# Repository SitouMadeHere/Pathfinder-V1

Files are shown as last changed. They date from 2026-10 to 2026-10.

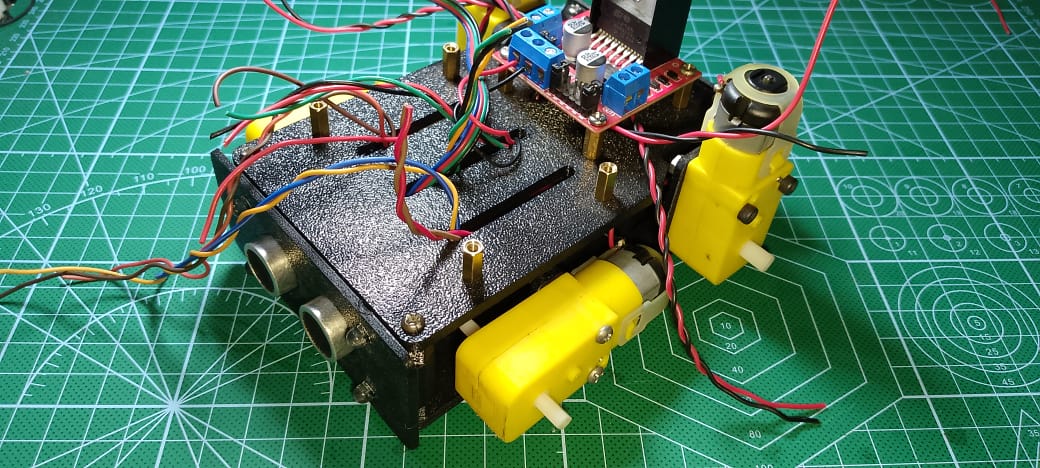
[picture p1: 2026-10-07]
Assembly2.jpeg

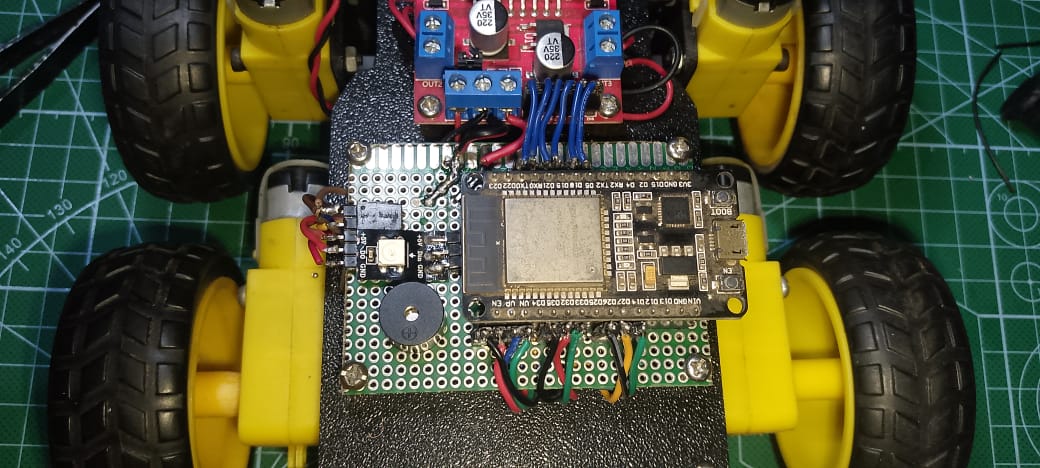
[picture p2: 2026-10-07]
Assembly1.jpeg

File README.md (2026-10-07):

# Pathfinder 

**Pathfinder** is an educational mobile robot designed as a learning by doing platform for exploring:

* Robotics
* Embedded programming
* Electronics
* Sensors and actuators
* Motor control
* 3D CAD
* FDM 3D printing
* Digital fabrication

The project is intended for **educational use and experimentation**.
> I've designed this robot for learning and experimentation and it a perfect educational project for learning by doing .

## Features

Pathfinder supports three operating modes:

* 🟢 **Automatic** — the robot detects obstacles, follows objects, and can detect drop-offs.
* 🔵 **Semi-automatic** — the operator controls the robot while the system helps maintain a minimum distance from obstacles.
* 🔴 **Manual** — full manual control without assistance.

The robot also includes:

* Ultrasonic obstacle detection
* Infrared drop-off detection
* Front and back signal LEDs
* WS2812B RGB status LED
* Buzzer
* Smartphone control via **Dabble app**
* 4-wheel drive

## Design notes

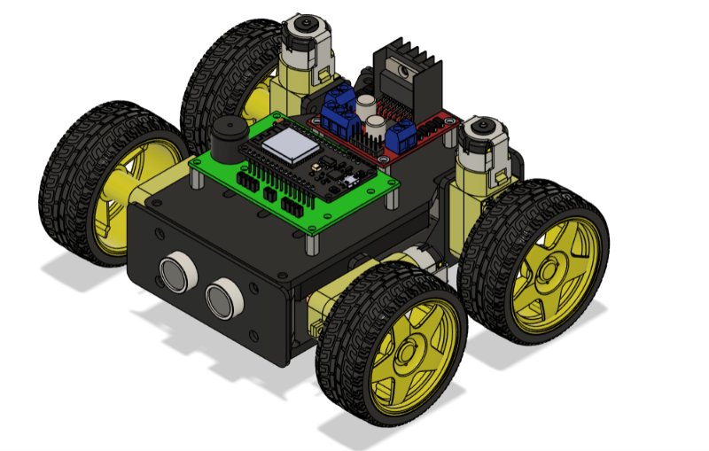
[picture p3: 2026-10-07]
view3.png

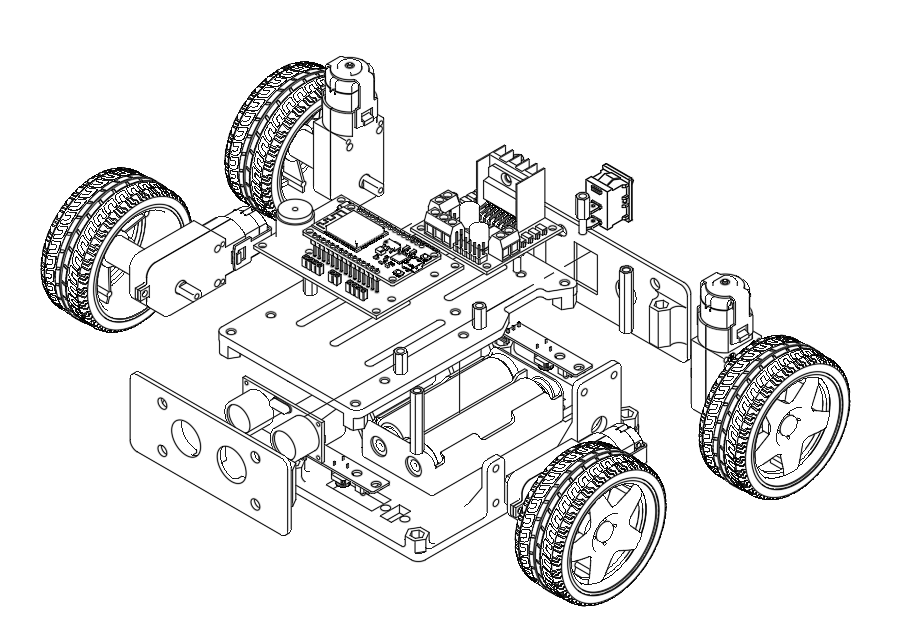
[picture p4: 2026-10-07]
view2.png

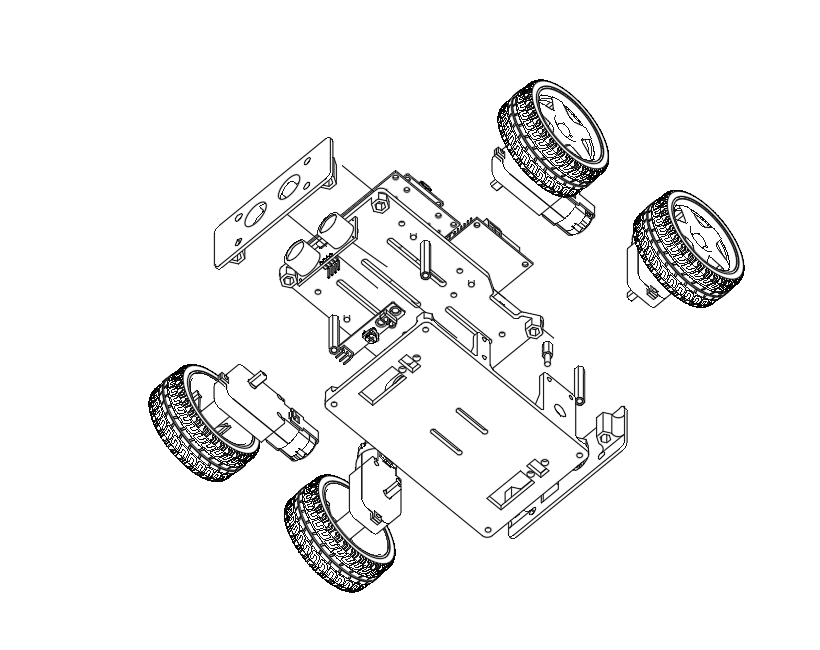
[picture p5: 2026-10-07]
view1.png

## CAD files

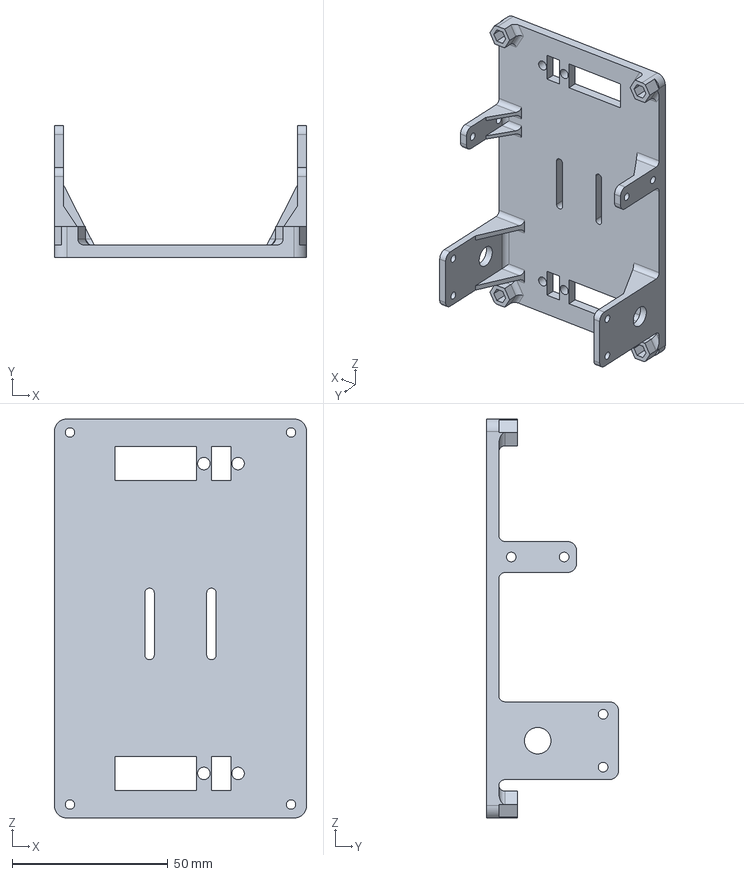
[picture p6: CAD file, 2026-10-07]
COMPOSENT/BASE.step
81.0 x 42.5 x 128.2 mm

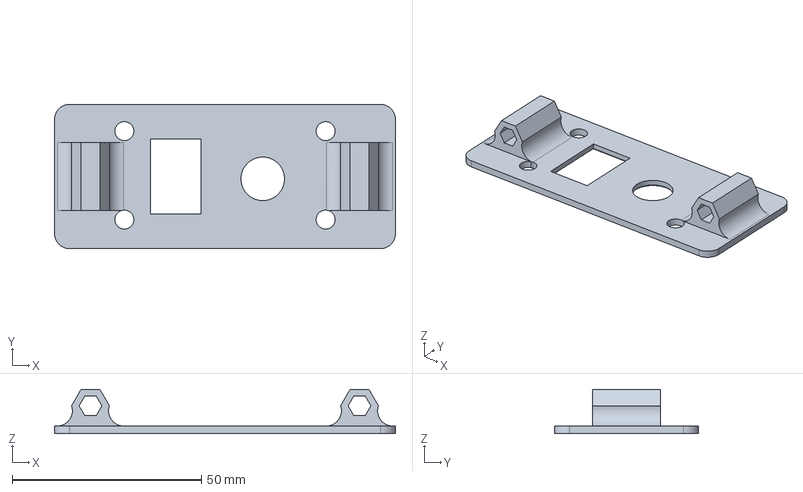
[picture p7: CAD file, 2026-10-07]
COMPOSENT/Back.step
90.0 x 38.1 x 11.7 mm

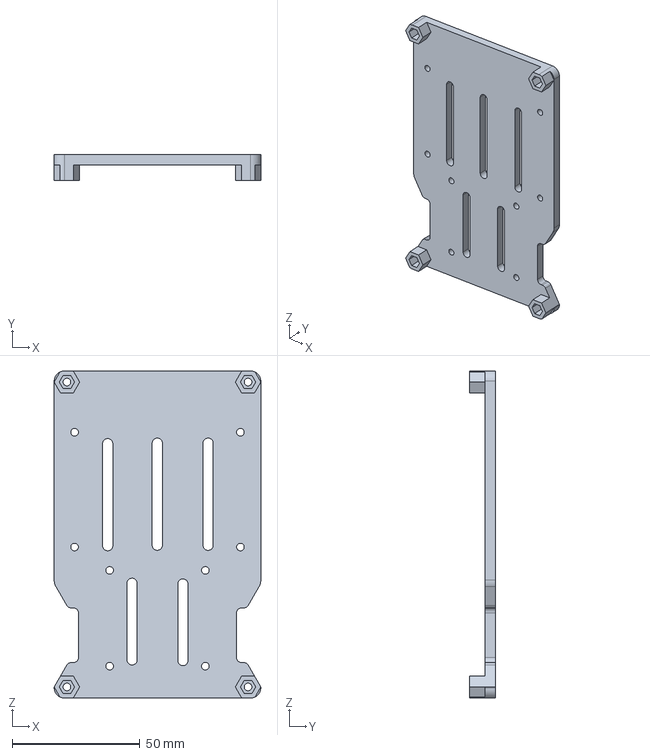
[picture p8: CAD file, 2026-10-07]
COMPOSENT/TOP FRAME.step
81.0 x 10.0 x 128.2 mm

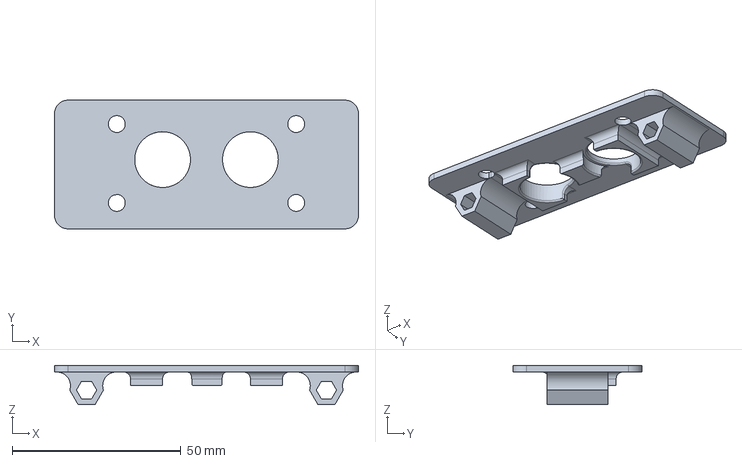
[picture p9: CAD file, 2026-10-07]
COMPOSENT/Front.step
90.0 x 38.1 x 11.7 mm

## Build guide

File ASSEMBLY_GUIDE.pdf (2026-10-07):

### B U I L D G U I D E

# Robot Pathfinder

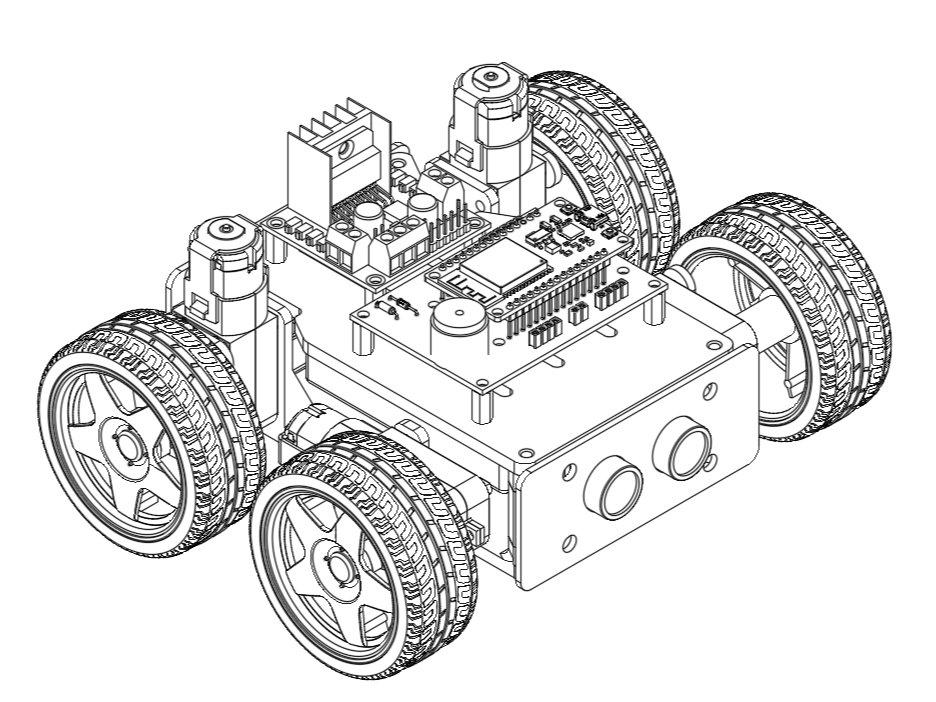
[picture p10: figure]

“Great discoveries and improvements invariably involve the cooperation of many minds.”

Alexander Graham Bell

P A T H F I N D E R | Build guide
Educational use | Page 2 / 13

# Contents

## 1. Introduction

This robot is intended for educational use only. It is named Pathfinder, after the Mars rover of the same name. Its overall dimensions are 180 × 150 × 90 mm and it incorporates numerous sensors dedicated to obstacle detection.

The robot can be used in three operating modes:

Mode | Description

Automatic

The robot is constantly alert and reacts to obstacles on its own: it detects obstacles, follows an object and can also detect drop-offs.

Semi-automatic (assisted
driving)

The operator drives the robot, but the system enforces minimum distances from obstacles to keep the robot and bystanders safe.

Manual (free driving) The operator keeps full control of the robot, with no restrictions.

Note Drop-off detection is disabled by default. To enable it, uncomment the corresponding section in the code.

## 2. Technical specifications

Characteristic | Specification
CAD software | Autodesk Fusion 360
Manufacturing process | 3D printing (FDM)
Recommended material | Filament PETG (preferred): excellent mechanical strength and good impact durability
Overall dimensions | 180 mm (length) × 150 mm (width) × 90 mm (height)

## 3. Bill of materials (BOM)

The table below lists all the components required to build the robot.

No. | Component | Reference / Description | Qty
1 | Microcontroller | ESP32 Dev Module | 1
2 | Motor | DC gear motor | 4
3 | Motor driver | L293N | 1
4 | Ultrasonic sensor | HC-SR04 | 1
5 | Infrared (IR) sensor | TCRT5000 | 2
6 | White LED | 5 mm, 5 V DC | 4
7 | Red LED | 5 mm, 5 V DC | 4
8 | RGB LED | WS2812B | 1
9 | Resistor | 220 Ω | 4
10 | Diode | 1N4007 | 1
11 | Female power jack | 2.1 × 5.5 mm, round, off-center | 1
12 | Mini ON/OFF switch | KCD11, 3 A / 250 V, 2 or 3 pins | 1
13 | Lithium battery | 18650 | 2
14 | Electrical wire | — | As needed
15 | Phillips or hex screw | M3-30 | 8
16 | Phillips or hex screw | M3-8 | 16
17 | Flat-head screw | M3-10 | 2
18 | Female-female hex standoff | M3-30 | 4
19 | Male-female hex standoff | M3-12 | 8
20 | Female pin header | 1 × 40 pins | 2
21 | Male pin header | 1 × 40 pins | 2

## 4. Assembly guide

Note All the parts that make up the robot’s structure are available in the “Composent” folder. If the parts fit tightly during assembly, do not hesitate to enlarge the holes slightly.

### Step 1: Mounting the motors

Solder wires of sufficient length onto each motor, then fasten them to the chassis with M3-30 screws, in the direction shown in the illustration.

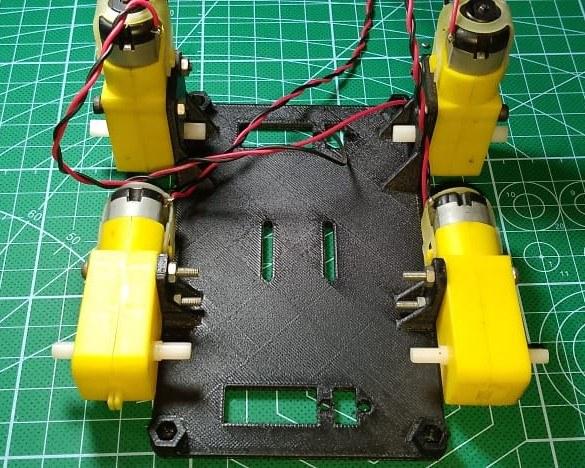
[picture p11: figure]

Figure 1 — Motors mounted on the chassis

### Step 2: Infrared sensors and battery holder

Solder electrical wires onto the infrared (IR) sensors, then screw them onto the chassis together with the M3-30 hex standoffs. Then attach the battery holder with M3 flat-head screws.

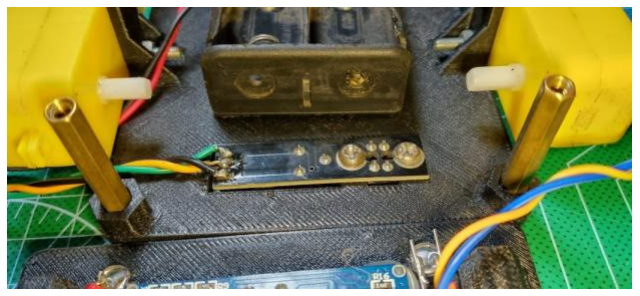
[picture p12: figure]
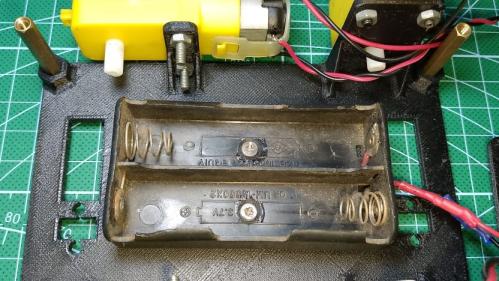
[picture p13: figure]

Figure 2 — IR sensors and M3-30 standoffs | Figure 3 — Battery holder

### Step 3: Fitting out the front and rear covers

Following the wiring diagram (section 5), solder the power jack, the switch and the four red LEDs, then install them in the rear cover. Next, solder the wires to the ultrasonic sensor and the four white LEDs, then install them in the front cover.

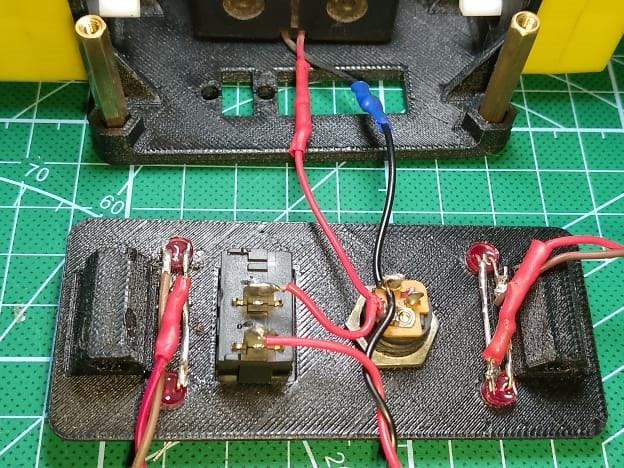
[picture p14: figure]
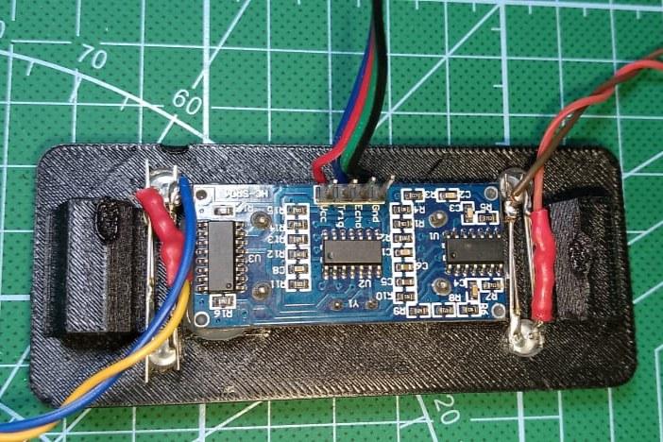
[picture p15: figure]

Figure 4 — Rear cover fitted | Figure 5 — Front cover fitted

Result At this point, the basic structure is mechanically ready and all front and rear peripherals are installed.

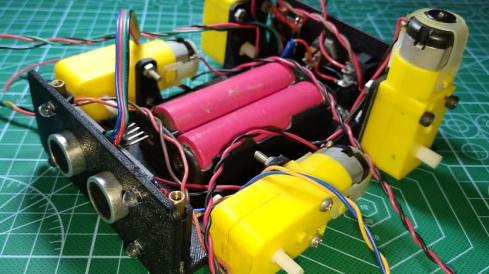
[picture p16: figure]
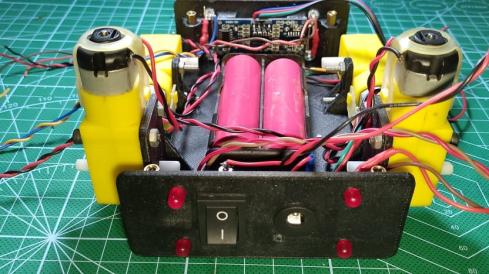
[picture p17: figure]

Figure 6 — Basic structure, front view | Figure 7 — Basic structure, rear view

### Step 4: Closing the chassis

Place the roof on the chassis, making sure all the wires come out: the motor wires through the rear slots and the other cables through the front slots. Screw in the eight M3-12 standoffs and attach the motor driver module (see the bill of materials). Finally, insert all the M3 screws and tighten them to permanently join the roof to the chassis.

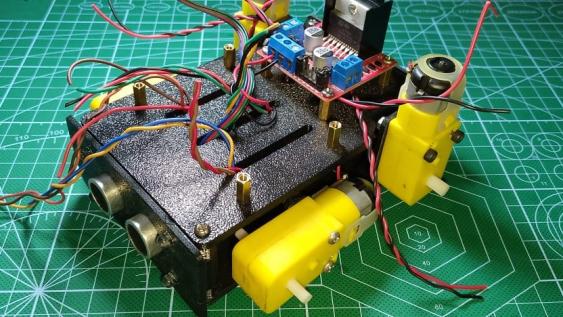
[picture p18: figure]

Figure 8 — Robot assembled with the roof and motor driver

## 5. Electronic circuit and main board

This section gathers all the diagrams and electrical connections of the robot.

### 5.1 Electronic circuit

Battery wiring
The diagram below shows the wiring of the battery (BT1), the power jack (J1) and the switch (SW1).

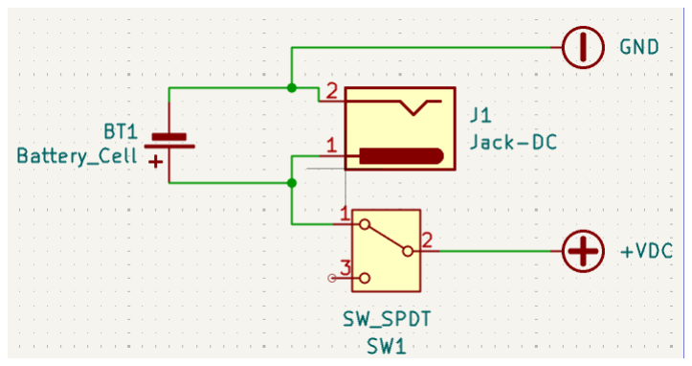
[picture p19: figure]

Figure 9 — Battery wiring diagram

LED wiring
The robot’s lighting system is divided into four (04) independent groups. Each group consists of two (02) LEDs wired in parallel, the whole being placed in series with a 220 Ω resistor.

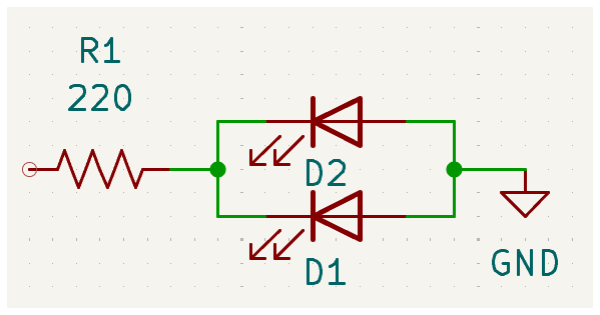
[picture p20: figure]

Figure 10 — Wiring diagram of one LED group

### 5.2 Main board

The main board is based on a 30-pin ESP32. All peripheral components are connected to it through male and female connectors carrying signals and power.

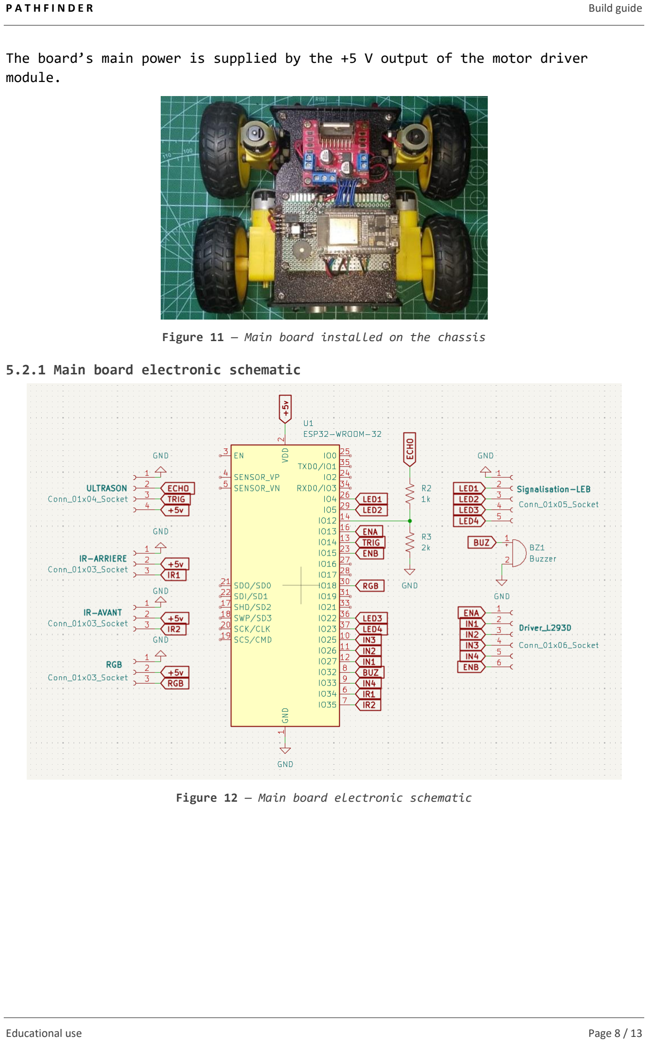
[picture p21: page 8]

The board’s main power is supplied by the +5 V output of the motor driver module.

Figure 11 — Main board installed on the chassis

### 5.2.1 Main board electronic schematic

Figure 12 — Main board electronic schematic

### 5.2.2 ESP32-to-driver connection

Connect a 6-pin female connector to a 6-pin male connector to link the ESP32 and the motor driver.

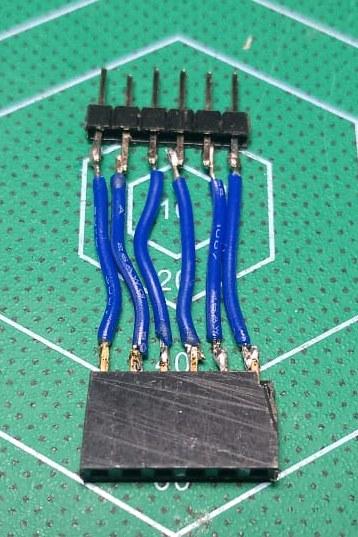
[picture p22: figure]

Figure 13 — 6-pin
connector

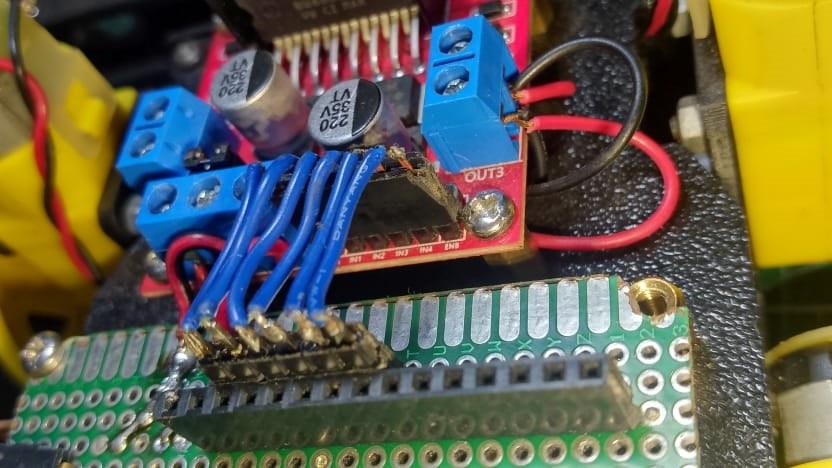
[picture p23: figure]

Figure 14 — Link to the motor driver

### 5.2.3 RGB LED connection

This is a WS2812B LED soldered onto a 3-pin male connector.

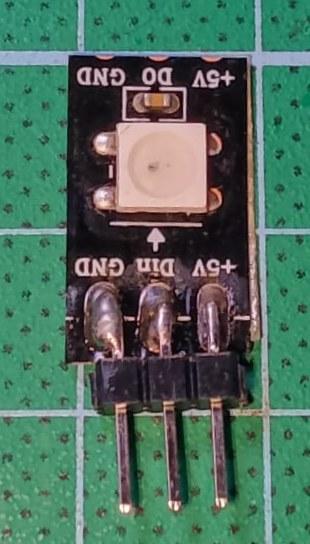
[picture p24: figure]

Figure 15 — WS2812B RGB LED module

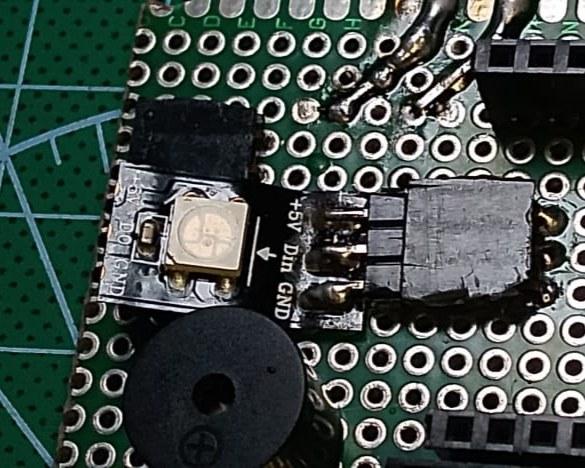
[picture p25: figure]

Figure 16 — Module installed on the main board

### 5.2.4 Signal LED connection

These are the LEDs built into the robot’s front and rear covers. They are connected to the main board through male-female connectors, following the wiring diagram defined on the board.

To wire the LEDs to the connector:

- Connect all the LED grounds (GND) together, then make a common solder joint to the connector’s ground pin.

- Then solder the LED control outputs to the adjacent connector pins, in the following order:

### 1. Front cover, left LED 2. Front cover, right LED 3. Rear cover, left LED 4. Rear cover, right LED

Important Respect the connection order and the LED polarity to ensure compatibility with the main board’s electrical schematic.

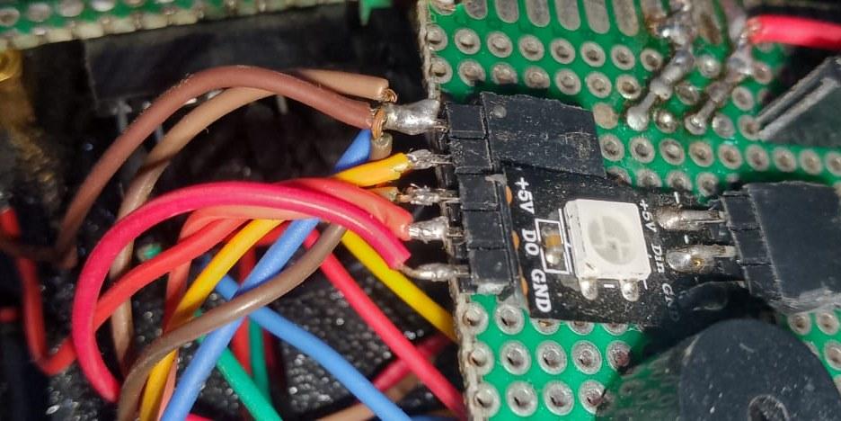
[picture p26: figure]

Figure 17 — Signal LED connections

### 5.3 IR sensor calibration

The infrared sensors must be calibrated to detect changes in distance between the robot and the surface it moves on. The goal is to identify any significant height difference indicating that part of the robot is over a void, or that the robot is abnormally raised.

Calibration consists of adjusting the potentiometer on each IR sensor to set the detection threshold correctly.

1. Power on the sensors and place the robot on a flat, uniform surface.
2. Observe the indicator LED on the IR module.

### 3. Slowly turn the potentiometer until the sensor reliably detects the surface

beneath the robot.

### 4. Gradually move the sensor toward an area simulating a void (table edge, a

black sheet held far away, or removing the surface under the sensor).

### 5. Adjust the potentiometer until the sensor’s state changes exactly when the

reference surface disappears.
6. Repeat several times, alternating the presence and absence of the surface, to check that detection is stable.
7. Make the same adjustment on the second IR sensor.

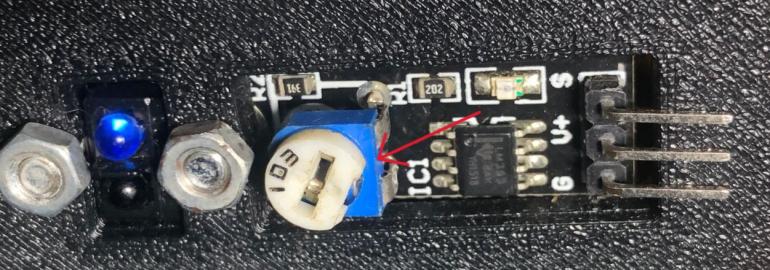
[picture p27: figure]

Figure 18 — TCRT5000 IR sensor and its adjustment potentiometer

## 6. Programs and source code

This section presents the programs required to run the robot. All files are available in the Code source folder.

### 6.1 Important tips

Uploading It is strongly recommended to remove the ESP32 board from its socket before uploading any code. Likewise, always switch the system off before putting it back.

Tests Run unit tests on each module to verify that it works correctly on its own.

Compilation Before compiling the code, install version 2.0.17 of the ESP32 package in the Boards Manager. If a newer version is installed, it is recommended to uninstall it to avoid compatibility conflicts.

### 6.2 Main programs

Program | Role
Auto-code | Manages the robot’s full autonomy.

Mode-code

Smartphone control, with navigation between three sub-modes identified by the RGB LED color:
Green: autonomous mode
Blue: semi-autonomous mode
Red: manual mode

## 7. App and control

The robot is controlled from the Dabble app, available on iOS and Android.

### 7.1 Connecting to the robot

After uploading the program to the board:

1. Open the Dabble app and go to the Gamepad section.
2. Connect to the device named PathFinder.

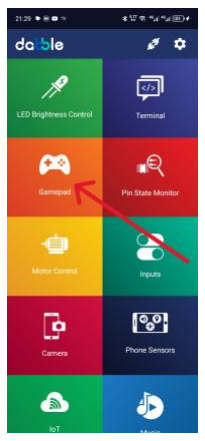
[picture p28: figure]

Figure 19 —
Gamepad
section in
Dabble

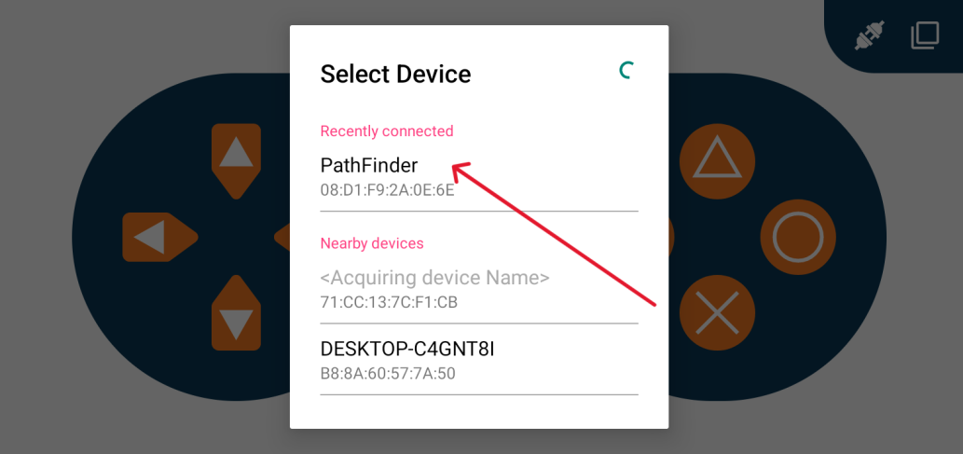
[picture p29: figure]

Figure 20 — Selecting the PathFinder device

### 7.2 Gamepad button functions

Button | Function

Arrow keys (UP, DOWN, LEFT,
RIGHT) | Steer the robot.

SELECT

Select the robot’s operating mode (manual, semi-automatic or automatic).

CROSS | Trigger the sound signal (buzzer).
TRIANGLE | Turn the front LEDs on and off.

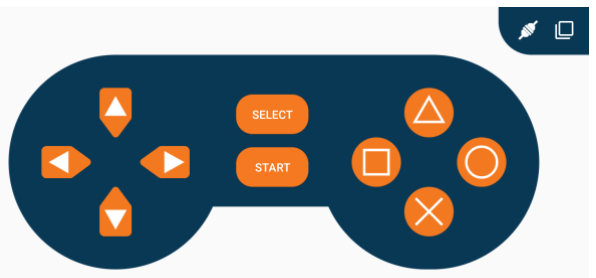
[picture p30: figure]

Figure 21 — Virtual gamepad of the Dabble app

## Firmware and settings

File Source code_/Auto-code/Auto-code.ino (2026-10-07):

// RELIER LES PINS ENABLE AU +5V
// Moteurs
#define IN1 27
#define IN2 26
#define IN3 25
#define IN4 33

// Ultrason
#define TRIG_PIN 14
#define ECHO_PIN 12

// CAPTEUR IR
#define FRONT_PIN 34 
#define BACK_PIN 35

// SIGNALISATION

#define LED1	4
#define LED2	5
#define LED3	22
#define LED4	23

// BUZZER
#define BUZZER 32

// Distance minimale avant obstacle (cm)
#define DISTANCE_SECURITE 5


// =========================
// FONCTIONS MOTEURS
// =========================

void avancer() {
  digitalWrite(IN1, 1);
  digitalWrite(IN2, 0);

  digitalWrite(IN3, 1);
  digitalWrite(IN4, 0);

  digitalWrite(LED1, 1);
  digitalWrite(LED2, 1);
  digitalWrite(LED3, 0);
  digitalWrite(LED4, 0);
}

void reculer() {
  digitalWrite(IN1, 0);
  digitalWrite(IN2, 1);

  digitalWrite(IN3, 0);
  digitalWrite(IN4, 1);

  digitalWrite(LED1, 0);
  digitalWrite(LED2, 0);
  digitalWrite(LED3, 1);
  digitalWrite(LED4, 1);
}

void tournerGauche() {
  digitalWrite(IN1, LOW);
  digitalWrite(IN2, HIGH);

  digitalWrite(IN3, HIGH);
  digitalWrite(IN4, LOW);

  digitalWrite(LED1, 0);
  digitalWrite(LED2, 1);
  digitalWrite(LED4, 1);
  digitalWrite(LED3, 0);
}

void tournerDroite() {
  digitalWrite(IN1, HIGH);
  digitalWrite(IN2, LOW);

  digitalWrite(IN3, LOW);
  digitalWrite(IN4, HIGH);

  digitalWrite(LED1, 1);
  digitalWrite(LED2, 0);
  digitalWrite(LED3, 1);
  digitalWrite(LED4, 0);
}

void stopRobot() {
  digitalWrite(IN1, LOW);
  digitalWrite(IN2, LOW);

  digitalWrite(IN3, LOW);
  digitalWrite(IN4, LOW);

  digitalWrite(LED1, 0);
  digitalWrite(LED2, 0);
  digitalWrite(LED3, 0);
  digitalWrite(LED4, 0);
}


// =========================
// MESURE ULTRASON
// =========================

float lireDistance() {

  digitalWrite(TRIG_PIN, LOW);
  delayMicroseconds(2);

  digitalWrite(TRIG_PIN, HIGH);
  delayMicroseconds(10);

  digitalWrite(TRIG_PIN, LOW);

  long duree = pulseIn(ECHO_PIN, HIGH, 30000);

  if (duree == 0) {
    return 999;
  }

  float distance = duree * 0.0343 / 2.0;

  return distance;
}

// =========================
// BIP BUZZER
// =========================
void bip(int duree) {
  digitalWrite(BUZZER, HIGH);
  delay(duree);
  digitalWrite(BUZZER, LOW);
  delay(60);
}


void setup() {

  Serial.begin(115200);

  pinMode(IN1, OUTPUT);
  pinMode(IN2, OUTPUT);
  pinMode(IN3, OUTPUT);
  pinMode(IN4, OUTPUT);

  pinMode(LED1, OUTPUT);
  pinMode(LED2, OUTPUT);
  pinMode(LED3, OUTPUT);
  pinMode(LED4, OUTPUT);

  pinMode(TRIG_PIN, OUTPUT);
  pinMode(ECHO_PIN, INPUT);

  pinMode(FRONT_PIN, INPUT);
  pinMode(BACK_PIN, INPUT);

  pinMode(BUZZER, OUTPUT);

  stopRobot();

  bip(100);
  delay(100);

  bip(100);
  delay(100);

  bip(250);

  delay(2000);

  Serial.println("Robot prêt");
}



void loop() {

  float distance = lireDistance();

  int front = digitalRead(FRONT_PIN);
  int back = digitalRead(BACK_PIN);

  Serial.print("Distance: ");
  Serial.print(distance);

  Serial.print("  front:");
  Serial.print(front);

  Serial.print("  back:");
  Serial.println(back);

  // =====================
  // ANTI-CHUTE
  // =====================

  /* 
  if (front == LOW || back == LOW) {

    Serial.println("VIDE DETECTE");

    stopRobot();
    delay(200);

    reculer();
    delay(500);

    tournerDroite();
    delay(700);

    stopRobot();
    delay(100);

    return;
  }*/

  // =====================
  // EVITEMENT OBSTACLE
  // =====================

  if (distance < DISTANCE_SECURITE) {

    Serial.println("OBSTACLE DETECTE");

    stopRobot();
    delay(200);

    reculer();
    delay(400);

    // Choix aléatoire du sens
    if (random(0, 2) == 0) {

      tournerGauche();
      delay(600);

    } else {

      tournerDroite();
      delay(600);
    }

    stopRobot();
    delay(100);
  }

  else {

    avancer();
  }

  delay(50);
}

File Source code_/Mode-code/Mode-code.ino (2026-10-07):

/*Avant de compiler le code veiller télécharger dans le gestionnaire de carte la version 2.0.17 de l’esp32 , 
si vous avez une version supérieur veiller la désinstaller d’abord*/ 

#define CUSTOM_SETTINGS
#define INCLUDE_GAMEPAD_MODULE
#include <DabbleESP32.h>
#include <Adafruit_NeoPixel.h>

// NEOPIXEL 
#define PIN 18
#define NUMPIXELS 1

Adafruit_NeoPixel pixel(NUMPIXELS, PIN, NEO_GRB + NEO_KHZ800);

// MOTEURS 
#define IN1 27
#define IN2 26
#define IN3 25
#define IN4 33

// ULTRASON 
#define TRIG_PIN 14
#define ECHO_PIN 12

// CAPTEURS IR 
#define FRONT_PIN 34
#define BACK_PIN 35

// LED 
#define LED1 4
#define LED2 5
#define LED3 22
#define LED4 23

// BUZZER 
#define BUZZER 32

// PARAMETRES 
#define DISTANCE_SECURITE_1 5
#define DISTANCE_SECURITE_2 3

// ETATS 
int mode = 0; // 0 Manuel, 1 Semi-auto, 2 Auto
bool lastSelect = false;

bool ledAvant = false;
bool lastTriangle = false;

// PROTOTYPES 
void Manuel();
void Semiauto();
void Auto();

void avancer();
void reculer();
void tournerDroite();
void tournerGauche();
void stopRobot();

float lireDistance();
void bip(int duree);
void updatePhares();

void setup() {

  Dabble.begin("PathFinder");

  pinMode(IN1, OUTPUT);
  pinMode(IN2, OUTPUT);
  pinMode(IN3, OUTPUT);
  pinMode(IN4, OUTPUT);

  pinMode(LED1, OUTPUT);
  pinMode(LED2, OUTPUT);
  pinMode(LED3, OUTPUT);
  pinMode(LED4, OUTPUT);

  pinMode(TRIG_PIN, OUTPUT);
  pinMode(ECHO_PIN, INPUT);

  pinMode(FRONT_PIN, INPUT);
  pinMode(BACK_PIN, INPUT);

  pinMode(BUZZER, OUTPUT);

  pixel.begin();
  pixel.setBrightness(255);

  pixel.setPixelColor(0, pixel.Color(255,0,0));
  pixel.show();

  randomSeed(micros());

  stopRobot();

  bip(100); delay(100);
  bip(100); delay(100);
  bip(250);

  delay(1500);
}

void loop() {

  Dabble.processInput();

  bool presentSelect = GamePad.isSelectPressed();
  bool presentTriangle = GamePad.isTrianglePressed();

  // PHARES 
  if (presentTriangle && !lastTriangle) {
    ledAvant = !ledAvant;
  }
  lastTriangle = presentTriangle;
  updatePhares();

  //  MODE 
  if (presentSelect && !lastSelect) {

    mode++;
    if (mode > 2) mode = 0;

    if (mode == 0) {
      pixel.setPixelColor(0, pixel.Color(255,0,0));
      bip(100);
    }
    else if (mode == 1) {
      pixel.setPixelColor(0, pixel.Color(0,0,255));
      bip(100); bip(100);
    }
    else {
      pixel.setPixelColor(0, pixel.Color(0,255,0));
      bip(100); bip(100); bip(100);
    }

    pixel.show();
    delay(200);
  }

  lastSelect = presentSelect;

  if (mode == 0) Manuel();
  else if (mode == 1) Semiauto();
  else Auto();

  digitalWrite(BUZZER, GamePad.isCrossPressed());
}

void updatePhares() {
  digitalWrite(LED1, ledAvant);
  digitalWrite(LED2, ledAvant);
}

void avancer() {
  digitalWrite(IN1, HIGH);
  digitalWrite(IN2, LOW);
  digitalWrite(IN3, HIGH);
  digitalWrite(IN4, LOW);

  digitalWrite(LED3, LOW);
  digitalWrite(LED4, LOW);
}

void reculer() {
  digitalWrite(IN1, LOW);
  digitalWrite(IN2, HIGH);
  digitalWrite(IN3, LOW);
  digitalWrite(IN4, HIGH);

  digitalWrite(LED3, HIGH);
  digitalWrite(LED4, HIGH);
}

void tournerDroite() {
  digitalWrite(IN1, LOW);
  digitalWrite(IN2, HIGH);
  digitalWrite(IN3, HIGH);
  digitalWrite(IN4, LOW);

  digitalWrite(LED3, LOW);
  digitalWrite(LED4, LOW);
}

void tournerGauche() {
  digitalWrite(IN1, HIGH);
  digitalWrite(IN2, LOW);
  digitalWrite(IN3, LOW);
  digitalWrite(IN4, HIGH);

  digitalWrite(LED3, LOW);
  digitalWrite(LED4, LOW);
}

void stopRobot() {
  digitalWrite(IN1, LOW);
  digitalWrite(IN2, LOW);
  digitalWrite(IN3, LOW);
  digitalWrite(IN4, LOW);

  digitalWrite(LED3, LOW);
  digitalWrite(LED4, LOW);
}

// ULTRASON 
float lireDistance() {

  digitalWrite(TRIG_PIN, LOW);
  delayMicroseconds(2);
  digitalWrite(TRIG_PIN, HIGH);
  delayMicroseconds(10);
  digitalWrite(TRIG_PIN, LOW);

  long duree = pulseIn(ECHO_PIN, HIGH, 30000);

  if (duree == 0) return 999;

  return duree * 0.0343 / 2.0;
}

void bip(int duree) {
  digitalWrite(BUZZER, HIGH);
  delay(duree);
  digitalWrite(BUZZER, LOW);
  delay(60);
}

void Manuel() {

  if (GamePad.isUpPressed()) avancer();
  else if (GamePad.isDownPressed()) reculer();
  else if (GamePad.isLeftPressed()) tournerGauche();
  else if (GamePad.isRightPressed()) tournerDroite();
  else stopRobot();
}

void Semiauto() {

  float d = lireDistance();

  if (d < DISTANCE_SECURITE_2) {
    stopRobot();
    delay(200);
    reculer();
    delay(400);
    stopRobot();
    return;
  }

  if (GamePad.isUpPressed()) avancer();
  else if (GamePad.isDownPressed()) reculer();
  else if (GamePad.isLeftPressed()) tournerGauche();
  else if (GamePad.isRightPressed()) tournerDroite();
  else stopRobot();
}

void Auto() {

  float d = lireDistance();

  if (d < DISTANCE_SECURITE_1) {

    stopRobot();
    delay(200);
    reculer();
    delay(400);

    if (random(0,2) == 0) tournerGauche();
    else tournerDroite();

    delay(500);
    stopRobot();
  }
  else {
    avancer();
  }
}

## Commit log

2026-10-07 3D parts
    [BASE.step, Back.step, Front.step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]
2026-10-07 Add Assembly guide
